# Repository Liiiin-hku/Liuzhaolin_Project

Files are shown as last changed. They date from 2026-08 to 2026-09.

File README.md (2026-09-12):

English · [中文](README_ZH.md)

# Compact Vision-Based Tactile Sensor for Robotic End Effectors

**Mechanical Design · Prototyping · Hardware Integration**<br>
**LIU Zhaolin | MSc Mechanical Engineering, The University of Hong Kong**

An engineering project bringing together compact sensor packaging, optical hardware, silicone fabrication and robotic mounting interfaces. Building on **9DTact**, I developed camera and enclosure adaptations, integrated illumination and internal routing, fabricated and assembled **two tactile sensor prototypes**, and built a test platform mechanically coupled to a **Robotiq FT300** six-axis force/torque sensor.

This portfolio follows the work from **CAD and component integration to physical prototypes and tactile contact demonstrations**, with engineering drawings, manufacturing records, software and experimental materials available to explore.

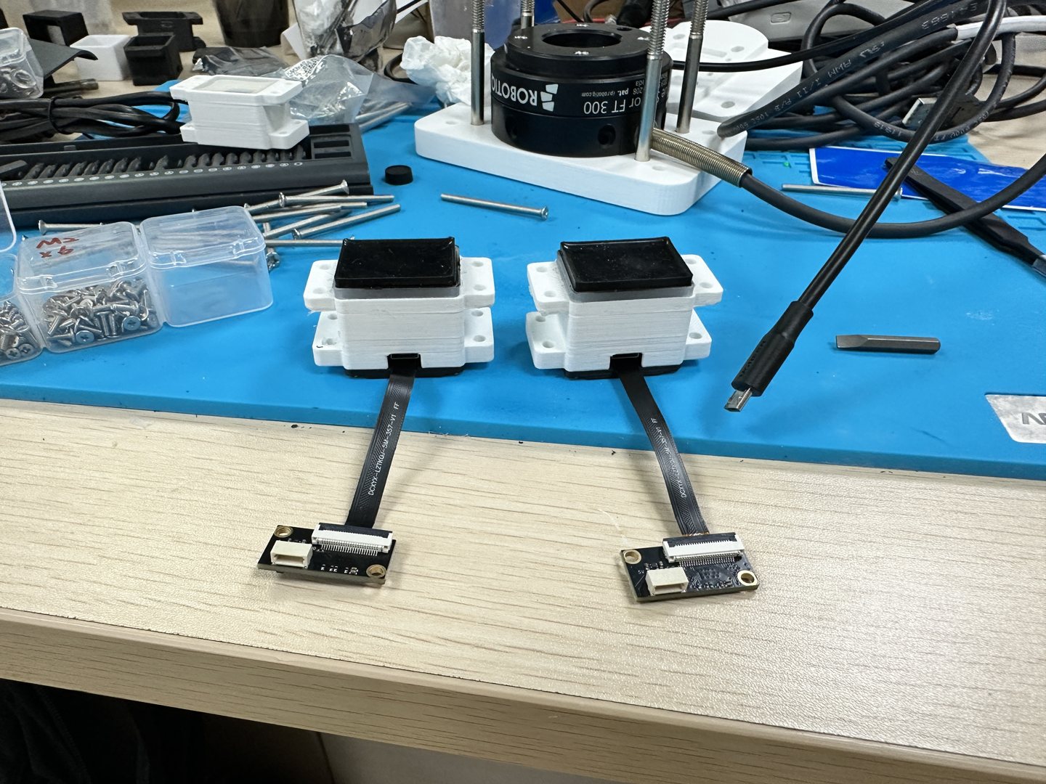
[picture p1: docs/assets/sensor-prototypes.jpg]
Two assembled tactile sensor prototypes with flexible camera cables and external decoder boards


*Two assembled prototypes showing the printed housings, tactile interfaces, flexible camera connections and external decoder boards.*

## Explore the project

| Start here | What you can review |
|---|---|
| [Mechanical design and hardware](03_Hardware/README.md) | Sensor parts, robotic mounting concepts, FT300 adapters, PCB integration and BOMs |
| [Prototype and contact demonstrations](05_Demos/README.md) | Short video extracts, original recordings and viewing instructions |
| [Engineering contributions](docs/PROJECT_OVERVIEW.md) | Responsibilities, design methods and supporting source files |
| [Software and system integration](02_Software/SOFTWARE_INDEX.md) | Camera calibration tools, reconstruction, FT300 workflows and ROS documentation |

**Quick hardware tour:** [22-second prototype video](05_Demos/Previews/hardware-preview.mp4) · [FT300 test platform](docs/assets/ft300-platform.jpg) · [Manufacturing photo collection](03_Hardware/08_Renders_and_Photos/PHOTO_CATALOG.md)

## My engineering contributions

| Workstream | Design and implementation |
|---|---|
| **Mechanical packaging** | Adapted the sensor housing, locating features, camera retention and optical-window support around an OV5640 imaging module and external decoder board. |
| **Optical and electrical integration** | Coordinated the lens, eight-LED illumination board and tactile window; arranged the flexible cable outlet and clearances around fasteners and the mechanical load path. |
| **Fabrication and assembly** | Prepared printed components and silicone moulds; carried out sealing, mixing, vacuum degassing, layered casting, curing, demoulding and prototype assembly. |
| **Image calibration and tactile experiments** | Implemented an interactive 7 × 9 calibration-point selection tool, worked on image rectification, and carried out spherical-indenter and contact-shape reconstruction experiments. |
| **Test fixtures and robotic interfaces** | Developed mounting adapters for the FT300-coupled platform and a two-finger gripper mounting concept, supported by CAD, STL files and assembly renderings. |
| **Software and ROS integration** | Organised sensor configurations and tools for FT300 acquisition, coordinate transforms, data checks, training/inference workflows and ROS Noetic operation. |

## Sensor architecture and compact packaging

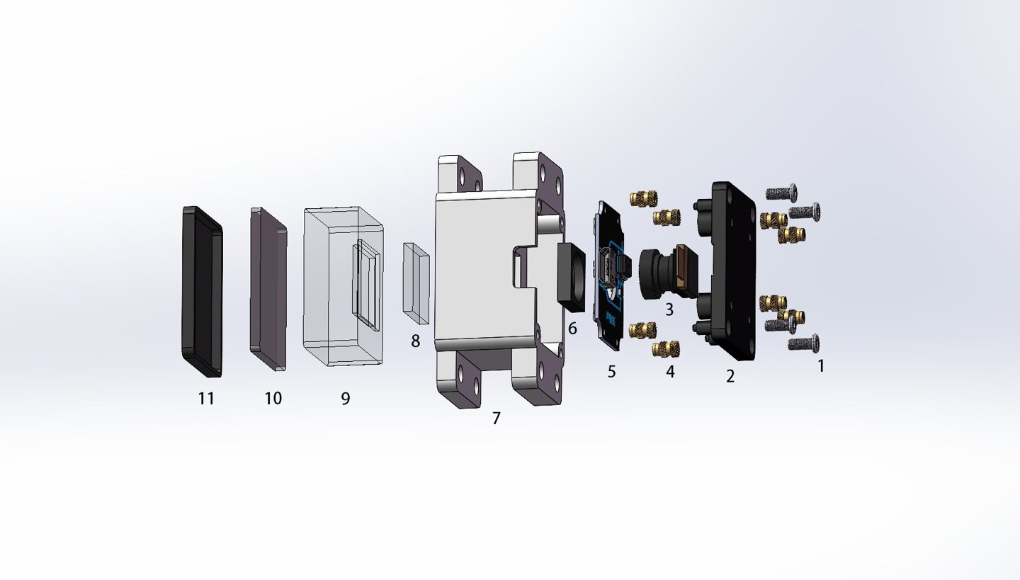
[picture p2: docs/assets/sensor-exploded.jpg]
Exploded view of the sensor housing, camera, illumination board, optical window and layered silicone interface


The mechanical design brings the camera, illumination, optical window and compliant tactile interface into a compact sensor head. Locating and retention features coordinate the optical stack, while an external decoder board connects through a flexible cable. Cable routing, assembly access and the mounting interface are considered alongside the sensor's optical requirements.

[Sensor CAD parts](03_Hardware/01_CAD_Source/SolidWorks_Parts/Optimized_Sensor/) · [STL models](03_Hardware/03_Print_Files_STL/README.md) · [Assembly and manufacturing records](03_Hardware/09_Manufacturing_Notes/ASSEMBLY_AND_MANUFACTURING_NOTES.md)

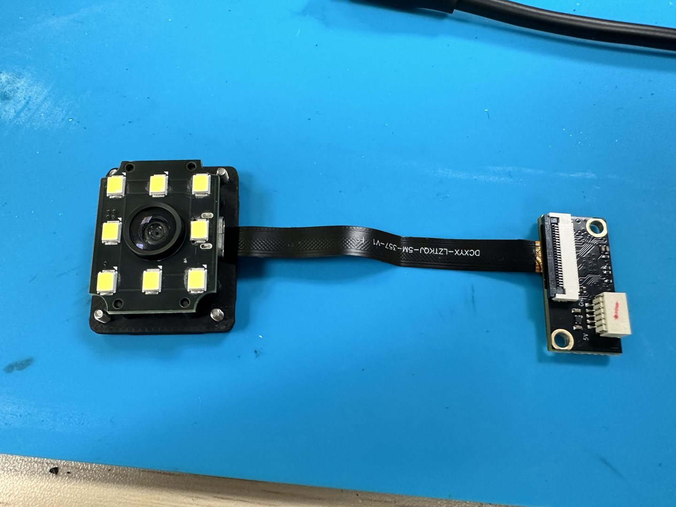
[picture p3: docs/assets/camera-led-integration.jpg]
Camera and eight-LED board integrated with the flexible cable and decoder


*Camera, illumination and cable integration. The LED PCB is reused from the upstream design; my work focuses on its mechanical placement, optical alignment and integration into the adapted sensor.*

## Silicone fabrication and prototype assembly

The tactile interface uses a layered silicone construction: a transparent **G50 support layer**, a translucent **G5 deformation layer** and a black **G25 contact layer**. The fabrication workflow covers mould preparation, seam sealing, mixing and vacuum degassing, successive casting and curing, followed by demoulding and final assembly.

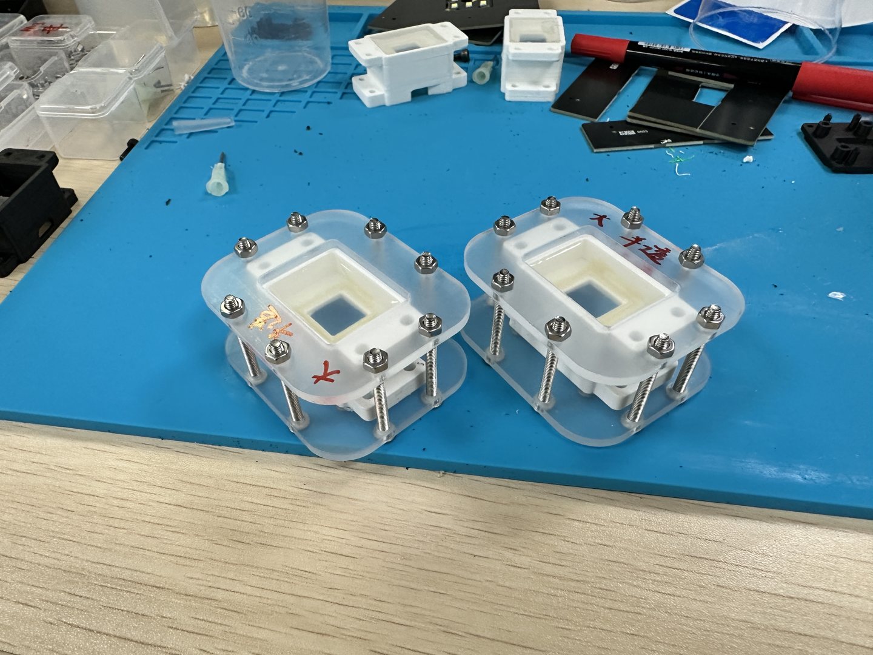
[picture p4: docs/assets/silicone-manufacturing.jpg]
Moulds and components used in the layered silicone fabrication process


The engineering archive includes **12 native SolidWorks part files, one LED-board assembly, nine STL files and three mould DXF files**, alongside component photographs, manufacturing records and bills of materials.

[Fabrication photographs](03_Hardware/09_Manufacturing_Notes/Process_Photos/) · [Mould drawings](03_Hardware/04_Engineering_Drawings/Acrylic_Mold/) · [BOM navigation](03_Hardware/BOM_INDEX.md)

## FT300 test platform and end-effector mounting

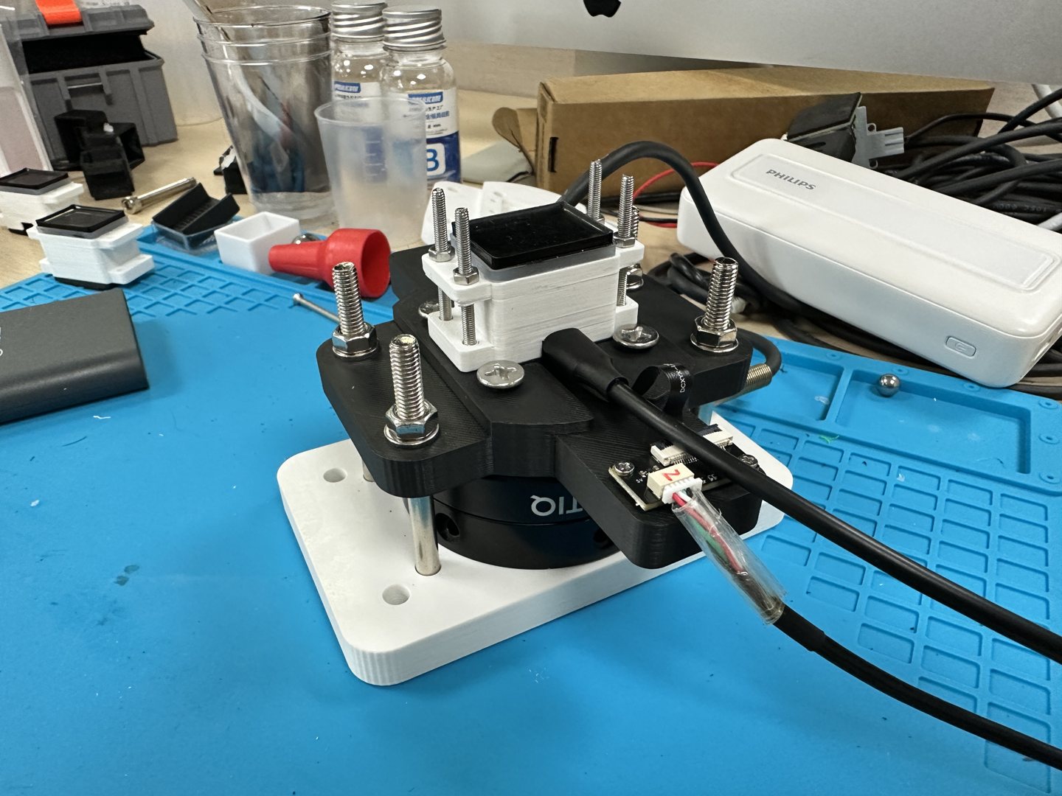
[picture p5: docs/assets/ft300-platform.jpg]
Custom tactile sensor mounted on a Robotiq FT300 mechanical test platform


The test fixture mechanically couples the tactile sensor to a **Robotiq FT300** reference force/torque sensor. Dedicated adapter parts provide a mounting interface and load-transfer path for contact experiments. The repository includes the physical setup, connection CAD and supporting acquisition workflows.

[FT300 adapter parts](03_Hardware/01_CAD_Source/SolidWorks_Parts/Test_Connections/) · [FT300 software setup](02_Software/Final_Repository_Snapshot/docs/06_FT300_SETUP.md)

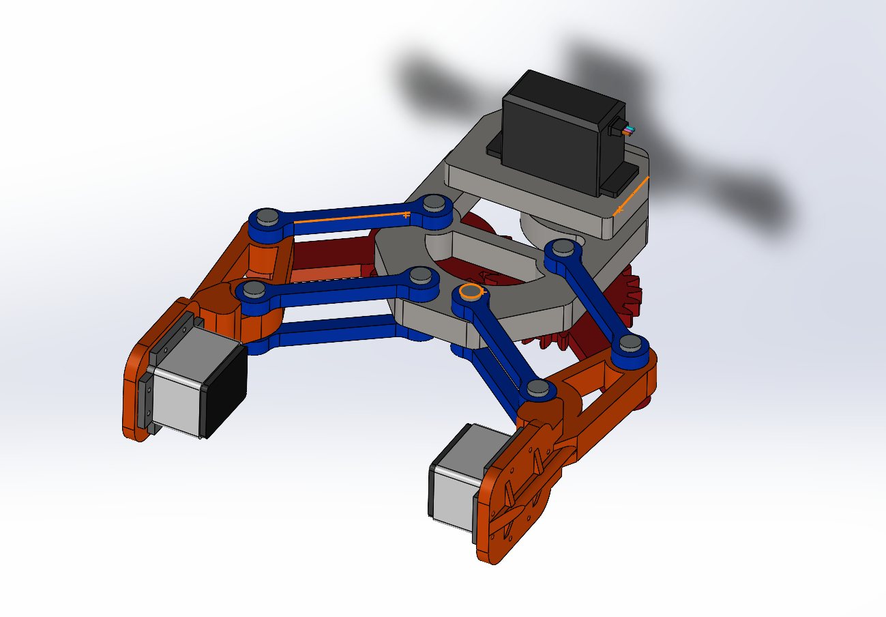
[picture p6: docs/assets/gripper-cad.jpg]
CAD rendering of a two-finger gripper concept with tactile sensor mounting interfaces


*Two-finger gripper mounting concept: left/right parts and sensor placement developed at the CAD stage.*

[Gripper CAD](03_Hardware/01_CAD_Source/SolidWorks_Parts/Gripper/) · [Gripper STL files](03_Hardware/03_Print_Files_STL/Existing_Source/Gripper/)

## Experiments and demonstrations

The project records show the assembled sensor, its connection to the computing environment, and tactile contact with an accompanying shape-reconstruction display. Calibration materials include point-selection images, spherical-indenter experiments and a reconstructed contact-shape example.

| Recording | View |
|---|---|
| Prototype appearance, illumination and connections | [22-second extract](05_Demos/Previews/hardware-preview.mp4) |
| Pressing interaction and shape response | [28-second extract](05_Demos/Previews/shape-preview.mp4) |
| Six-axis vector interface demonstration | [28-second extract](05_Demos/Previews/vector-preview.mp4) |

Open a video file and select **View raw** or **Download raw file** to watch. The [demo guide](05_Demos/README.md) provides original recordings, timestamps and interpretation. [Technical validation notes](docs/VALIDATION_STATUS.md) document experiment conditions and software checks.

## Engineering archive

| Area | Contents |
|---|---|
| [Academic work](01_Academic/ACADEMIC_INDEX.md) | Dissertation, presentation, project reports and reference index |
| [Software](02_Software/SOFTWARE_INDEX.md) | Frozen source snapshot, installation and operating guides |
| [Hardware](03_Hardware/README.md) | CAD, STL, DXF, PCB, BOM, photographs and manufacturing records |
| [Calibration and experiment materials](04_Data_and_Models/DATA_MODEL_INDEX.md) | Calibration files, process images and contact-shape results |
| [Demonstrations](05_Demos/README.md) | Video covers, short extracts and original recordings |

The documented software environment is **Ubuntu 20.04 / Python 3.8 / ROS Noetic**. Start with the [installation and workflow guide](02_Software/SOFTWARE_INDEX.md).

## Project background and attribution

This portfolio presents the engineering work associated with my master's dissertation, *Development of a Compact Vision-Based Tactile Sensor for Robotic End Effectors*.

The project builds on the [9DTact sensing methods and open-source design](https://github.com/linchangyi1/9DTact). Upstream algorithms, reference hardware and licences are retained with their attribution; project-specific adaptations and integration tools are documented in the source snapshot. The software reference commit is `98ebb7da0010df27ef634f9868e557d77fa73ec5`.

[Project timeline](PROGRESS_TIMELINE.md) · [Version provenance](VERSION_FREEZE.md) · [Rights and attribution](docs/RIGHTS_AND_ATTRIBUTION.md) · [File manifest](SUBMISSION_MANIFEST.csv)

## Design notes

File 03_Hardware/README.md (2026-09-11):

# 结构设计、样机与硬件资料

[返回首页](../README.md) · [个人贡献证据](../docs/PROJECT_OVERVIEW.md)

这里展示从结构适配到实物制造的工程材料。原始 CAD、装配体、PCB、BOM 和制造照片保持原路径；展示图片是压缩副本。

传感器结构爆炸图

## 先看结构和实物

| 主题 | 工程入口 | 可直接浏览的证据 |
|---|---|---|
| 外壳、基座、窗口和隔离环 | [Optimized_Sensor](01_CAD_Source/SolidWorks_Parts/Optimized_Sensor/) | [双传感器成品](08_Renders_and_Photos/Completed_Hardware/completed_dual_custom_sensors.jpg) |
| FT300 与传感器连接基座 | [Test_Connections](01_CAD_Source/SolidWorks_Parts/Test_Connections/) | [FT300 耦合平台](08_Renders_and_Photos/Test_Setups/sensor_ft300_calibration_fixture.jpg) |
| 双指夹爪安装方案 | [左右夹爪 CAD](01_CAD_Source/SolidWorks_Parts/Gripper/) | [装配渲染](08_Renders_and_Photos/Assembly_and_Design/custom_gripper_assembly_render.png) |
| 3D 打印交付 | [9 个 STL 与映射](03_Print_Files_STL/README.md) | [打印件照片](09_Manufacturing_Notes/Process_Photos/printed_mold_and_housing_parts.jpg) |
| 分层浇注模具 | [3 个亚克力 DXF](04_Engineering_Drawings/Acrylic_Mold/) | [模具及硅胶制造记录](09_Manufacturing_Notes/ASSEMBLY_AND_MANUFACTURING_NOTES.md) |

原生 SolidWorks 为 **12 个零件和 1 个 LED 板装配体**，不等同于完整的自定义传感器或夹爪装配工程。STL 为 9 个，其中 7 个为转换交付、2 个为既有夹爪 STL。本次未执行 SolidWorks 打开、重建、单位或装配引用检查；没有重命名或移动 CAD。

## PCB、照明和 BOM

- [PCB 工程、Gerber、贴片坐标与电子照片](07_PCB_and_Electronics/ELECTRONICS_INDEX.md)
- [主 BOM 与电子 BOM](BOM_INDEX.md)：主表 38 行材料/采购条目；电子表 4 行器件类型；贴片表 11 个位置。
- [电子实物：相机、LED 板、排线与解码板](07_PCB_and_Electronics/Photos/sensor_electronics_components.jpg)

主 BOM 用于器件和制造资料定位，采购单价与汇总并不代表单个样机的物料成本。保留的 PCB 工程、Gerber ZIP、电子 BOM 与贴片表与上游快照相同；个人工作按照明安装和硬件集成说明。[文件来源核对](../docs/HARDWARE_PROVENANCE.csv)

## 制造与装配

从 [制造记录](09_Manufacturing_Notes/ASSEMBLY_AND_MANUFACTURING_NOTES.md) 查看模具封边、混合脱泡、分层浇注、固化脱模和装配过程。完整 [图片目录](08_Renders_and_Photos/PHOTO_CATALOG.md) 与 [来源映射](08_Renders_and_Photos/PHOTO_SOURCE_MAPPING.csv) 保留原图线索。

仍缺与最终 CAD/BOM 逐项对应并经复核的装配步骤、完整端到端接线图及统一供电范围说明。实际制造前需要核实尺寸、孔隙配合、极性与电源条件；这些限制详见 [验证状态](../docs/VALIDATION_STATUS.md)。

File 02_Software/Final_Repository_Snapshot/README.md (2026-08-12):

# 9DTact + FT300 Custom Tactile Sensor Project

[Chinese README](README_CN.md) | [Version and validation status](VERSION_INFO.md)

This repository is the graduation-project delivery for two custom optical tactile
sensors derived from the 9DTact workflow. It brings together camera calibration,
3D surface reconstruction, synchronized FT300 data acquisition, dataset preparation,
six-axis force-model training, standalone tactile inference, and ROS 1 integration.

The repository is organized for a beginner to complete one sensor at a time. Sensor 1
and Sensor 2 keep separate calibration, dataset, configuration, and model paths. The
active sensor is selected explicitly before calibration, acquisition, reconstruction,
training, or inference.

> **Validation boundary:** repository structure and static checks can be verified on
> Windows. Camera mapping, depth response, FT300 acquisition, ROS nodes, trained-model
> accuracy, and combined hardware behavior still require Ubuntu 20.04 tests with the
> physical devices. No Windows result is presented as a hardware pass.

## Project scope

| Stage | Included implementation | Current evidence |
|---|---|---|
| Sensor selection | Isolated Sensor 1 and Sensor 2 templates and activation tool | Static file/configuration checks |
| Camera calibration | Automatic calibration plus a reviewed 7 x 9 manual-point workflow | Active arrays exist for both sensors; Sensor 2 has manual-point provenance |
| Depth-to-shape conversion | Active hybrid official depth LUT experiment | File integrity verified; physical accuracy remains unverified |
| Shape reconstruction | Standalone OpenCV/Open3D workflow and ROS wrapper | Requires Ubuntu camera test |
| FT300 acquisition | Synchronized tactile image and `WrenchStamped` label collection | Requires an external FT300 ROS driver and hardware test |
| Dataset processing | Integrity checks, normalization, and two object-disjoint split modes | Offline tools included |
| Force training | ResNet18 smoke-test path and DenseNet169 full-training path | Training code included; datasets and trained weights are excluded |
| Force inference | Standalone and ROS six-axis inference | Requires a sensor-specific checkpoint and Ubuntu test |
| ROS integration | Catkin package and six launch workflows | Static XML/Python checks only |

## Important calibration facts

- Each sensor resolves `row_index.npy`, `col_index.npy`, and `position_scale.npy`
  through a sensor-specific active path. The current three core arrays are
  byte-identical between those paths; they are not evidence of independently derived
  camera mappings.
- Both active sensors currently use the same official upstream depth lookup table:
  `Original/shape_reconstruction/calibration/sensor_1/depth_calibration/Pixel_to_Depth.npy`.
- The shared LUT SHA-256 is
  `19C9F3514DCE402D8E710079757394B5445B74E7AFBDD2459DE43798676CB4FF`.
- This is an **experimental hybrid calibration**, not an independently measured,
  precise depth calibration of either custom sensor.
- Running `shape_reconstruction/_2_Sensor_Calibration.py` trains and replaces the
  active sensor's LUT. Doing so intentionally leaves the hybrid-LUT state. Back up
  the current LUT first; if the hybrid state is restored, rerun
  `python tools/verify_hybrid_calibration.py`.
- The latest Ubuntu archive records `camera_channel: 2` and a reconstruction crop of
  `[280, 380]` for both sensors. `/dev/videoX` numbering is host-dependent and must be
  checked on every Ubuntu computer. Force-model `img_size` is aligned to `[280, 380]`.

## Supported baseline

- Ubuntu 20.04 LTS
- Python 3.8
- ROS Noetic (ROS 1)
- OpenCV, NumPy, SciPy, Open3D, and PyYAML from the pinned core requirements
- PyTorch 2.0.1 and torchvision 0.15.2 for training and inference
- An external FT300 ROS driver that publishes `geometry_msgs/WrenchStamped`

The repository does not bundle an FT300 hardware driver and does not claim that a
particular vendor driver officially supports ROS Noetic. Confirm the driver and robot
controller combination in the target laboratory. The raw wrench topic is configurable;
the example default is `/robotiq_ft_wrench`.

## Beginner quick start

### 1. Install the core Ubuntu environment

```bash
cd <LOCAL_PROJECT_ROOT>
bash scripts/install_core_ubuntu20.sh
source custom_9dtact/.venv/bin/activate
python scripts/verify_installation.py --profile core
```

For ROS or training dependencies, continue with
[Ubuntu 20.04 installation](docs/01_INSTALLATION_UBUNTU20.md). Do not copy a virtual
environment from another computer.

### 2. Select and check one sensor

```bash
cd <LOCAL_PROJECT_ROOT>/custom_9dtact
python tools/activate_sensor.py --sensor-id 1
python tools/check_sensor_setup.py --sensor-id 1
```

Use `--sensor-id 2` for Sensor 2. Activation copies the selected templates into the
active `shape_config.yaml` and `force_config.yaml` files and stores local runtime state
under `.runtime/`.

### 3. Confirm the camera device on Ubuntu

```bash
v4l2-ctl --list-devices
ls -l /dev/video*
```

If the correct device is not channel 2 on that host, edit the selected persistent
template in `custom_9dtact/configs/`, then activate the sensor again. Do not edit only
the generated active configuration.

### 4. Validate or rebuild camera calibration

Automatic workflow:

```bash
cd <LOCAL_PROJECT_ROOT>/custom_9dtact/shape_reconstruction
python _1_Camera_Calibration.py
```

Manual 7 x 9 workflow, with new reference/sample capture:

```bash
python manual_camera_calibration_v2.py --capture
```

Click 63 grid points in row-major order. Press `A` to toggle snapping, use right-click
or `U` to undo, press Enter to preview, and press lowercase `s` to save. The tool makes
a timestamped internal backup before replacing active camera arrays. See
[Camera calibration](docs/03_CAMERA_CALIBRATION.md) before applying new outputs.

### 5. Check the active hybrid depth LUT

```bash
cd <LOCAL_PROJECT_ROOT>/custom_9dtact
python tools/verify_hybrid_calibration.py
```

The check proves file identity and array validity only. It does not prove the physical
depth response of either custom sensor.

### 6. Run standalone 3D shape reconstruction

```bash
cd <LOCAL_PROJECT_ROOT>/custom_9dtact
python tools/activate_sensor.py --sensor-id 1
python tools/check_sensor_setup.py --sensor-id 1
cd shape_reconstruction
python _3_Shape_Reconstruction.py
```

Repeat in a fresh terminal with Sensor 2 selected. Record the no-contact surface,
light press, medium press, release recovery, and contact-location response separately.

### 7. Acquire FT300-labelled data

FT300 measurements are ground-truth labels for data collection, training, and
validation. Start the ROS master, camera/image publisher, and external FT300 driver
before starting the collector. Validate the wrench topic first:

```bash
cd <LOCAL_PROJECT_ROOT>/custom_9dtact
python tools/check_ft300_topic.py --topic /robotiq_ft_wrench
```

Then follow [FT300 setup](docs/06_FT300_SETUP.md) and
[data collection](docs/07_DATA_COLLECTION.md). Stop recording before stopping the
collector, then stop the camera and FT300 driver, and stop `roscore` last.

### 8. Prepare, train, and evaluate

Keep the two sensor datasets separate. Validate a dataset before training:

```bash
cd <LOCAL_PROJECT_ROOT>/custom_9dtact
python tools/check_dataset_integrity.py \
  --dataset-root Dataset_sensor_1 \
  --require-normalized \
  --check-splits
```

Run a short ResNet18 pipeline test before a long DenseNet169 run. Trained tactile
inference uses camera images and the selected neural-network checkpoint; FT300 is not
required during normal inference. FT300 remains necessary when collecting new labels
or comparing predictions against physical ground truth.

### 9. Run in ROS

The catkin package is located at
`custom_9dtact/ros_ws/src/9dtact_ft300_ros`. Its six launch entry points are:

- `sensor1_shape.launch`
- `sensor2_shape.launch`
- `ft300_collection.launch`
- `force_estimation.launch`
- `shape_force_demo.launch`
- `compare_prediction_with_ft300.launch`

Build, source, and use the launch file that matches the intended stage. Review the
actual launch-file arguments before starting hardware. See
[ROS workflow](docs/11_ROS_WORKFLOW.md).

## Documentation map

1. [Project overview](docs/00_PROJECT_OVERVIEW.md)
2. [Ubuntu 20.04 installation](docs/01_INSTALLATION_UBUNTU20.md)
3. [Sensor configuration](docs/02_SENSOR_CONFIGURATION.md)
4. [Camera calibration](docs/03_CAMERA_CALIBRATION.md)
5. [Sensor/depth calibration](docs/04_SENSOR_CALIBRATION.md)
6. [Shape reconstruction](docs/05_SHAPE_RECONSTRUCTION.md)
7. [FT300 setup](docs/06_FT300_SETUP.md)
8. [Data collection](docs/07_DATA_COLLECTION.md)
9. [Data processing](docs/08_DATA_PROCESSING.md)
10. [Model training](docs/09_MODEL_TRAINING.md)
11. [Force estimation](docs/10_FORCE_ESTIMATION.md)
12. [ROS workflow](docs/11_ROS_WORKFLOW.md)
13. [Troubleshooting](docs/12_TROUBLESHOOTING.md)
14. [Project tree](docs/13_PROJECT_TREE.md)
15. [Hybrid depth-LUT experiment record](docs/ORIGINAL_DEPTH_LUT_EXPERIMENT_2026-07-25.md)

## Repository protection and excluded artifacts

- Treat `Original/` as a byte-preserved, read-only upstream snapshot.
- Work in `custom_9dtact/` and repository-level documentation only.
- Datasets, trained weights, local runtime state, caches, logs, temporary outputs,
  and generated training bundles are intentionally excluded from Git.
- Do not exchange calibration files, datasets, or model paths between Sensor 1 and
  Sensor 2.
- Back up active calibration and data before every hardware experiment.

## Citation and license

The custom work is distributed under the repository [LICENSE](LICENSE). Upstream
attribution and third-party notices are recorded in [NOTICE.md](NOTICE.md). When this
project is used in academic work, cite the upstream 9DTact project and the relevant
hardware/software sources described there.

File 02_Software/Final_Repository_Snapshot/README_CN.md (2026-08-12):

# 9DTact + FT300 自制触觉传感器项目

[English README](README.md) | [版本与验证状态](VERSION_INFO.md)

本仓库是面向毕业设计交付的双自制光学触觉传感器代码工程，基于 9DTact 工作流，覆盖摄像头标定、
三维形状重建、FT300 同步数据采集、数据集处理、六维力模型训练、独立触觉推理和 ROS 1 集成。

Sensor 1 与 Sensor 2 的标定文件、配置、数据集和模型目录彼此隔离。标定、采集、重建、训练或推理前，
一次只激活一个传感器。

> **验证边界：** Windows 已完成的内容属于仓库结构和静态检查，不代表相机、深度响应、FT300、ROS、
> 模型精度或组合硬件测试通过。相关结论仍需在 Ubuntu 20.04 连接真实硬件后逐项验证。

## 当前项目状态

| 环节 | 仓库内容 | 当前证据 |
|---|---|---|
| 传感器切换 | Sensor 1/2 独立模板与激活工具 | 已完成静态配置检查 |
| 摄像头标定 | 自动流程和 7 x 9 手动点选流程 | 两个传感器活动数组存在；Sensor 2 有手动点来源记录 |
| 深度到形状转换 | 官方深度 LUT 混合实验 | 文件一致性通过；物理准确性待实测 |
| 三维形状重建 | 独立程序与 ROS 封装 | 待 Ubuntu 相机实测 |
| FT300 采集 | 图像与 `WrenchStamped` 六维力同步采集 | 需要外部 FT300 驱动和硬件实测 |
| 数据处理 | 完整性检查、归一化以及两种按物体隔离的划分方式 | 离线工具已提供 |
| 力模型训练 | ResNet18 短训练和 DenseNet169 正式训练流程 | 代码已提供；数据集和权重未包含在仓库中 |
| 力推理 | 独立与 ROS 六维力推理 | 需要传感器对应权重并在 Ubuntu 验证 |

## 标定状态必须如实理解

- Sensor 1 和 Sensor 2 分别通过各自的活动路径使用 `row_index.npy`、`col_index.npy` 和
  `position_scale.npy`。当前两个路径中的三份核心数组内容逐字节相同，因此不能据此描述为两个独立生成的
  摄像头映射。
- 两个传感器当前活动的 `Pixel_to_Depth.npy` 都来自上游只读快照中的
  `Original/shape_reconstruction/calibration/sensor_1/depth_calibration/Pixel_to_Depth.npy`。
- 共享 LUT 的 SHA-256 为
  `19C9F3514DCE402D8E710079757394B5445B74E7AFBDD2459DE43798676CB4FF`。
- 当前方案属于实验性混合标定，不等同于分别对两个自制传感器完成了精确深度标定。
- 执行 `shape_reconstruction/_2_Sensor_Calibration.py` 会训练并替换当前活动传感器的 LUT，
  因此会主动退出混合官方 LUT 状态。执行前应备份；如需恢复混合方案，恢复后再次运行
  `python tools/verify_hybrid_calibration.py`。
- 最新 Ubuntu 压缩包中两个传感器均记录 `camera_channel: 2`，形状裁剪尺寸均为 `[280, 380]`，
  力模型 `img_size` 已与其对齐。`/dev/videoX` 编号取决于具体电脑，必须在目标 Ubuntu 主机重新确认。

## 环境基线

- Ubuntu 20.04 LTS
- Python 3.8
- ROS Noetic
- 核心依赖：OpenCV、NumPy、SciPy、Open3D、PyYAML
- 训练依赖：PyTorch 2.0.1、torchvision 0.15.2、TensorBoard
- 外部 FT300 ROS 驱动：必须发布可配置话题类型 `geometry_msgs/WrenchStamped`

仓库不包含 FT300 硬件驱动，也不声称某个厂商驱动获得 ROS Noetic 官方支持。默认示例原始力话题为
`/robotiq_ft_wrench`，实际话题可以配置。

## 新手快速流程

### 1. 安装核心环境

```bash
cd <LOCAL_PROJECT_ROOT>
bash scripts/install_core_ubuntu20.sh
source custom_9dtact/.venv/bin/activate
python scripts/verify_installation.py --profile core
```

ROS 与训练依赖见 [Ubuntu 20.04 安装说明](docs/01_INSTALLATION_UBUNTU20.md)。不要从另一台电脑复制虚拟环境。

### 2. 激活并检查一个传感器

```bash
cd <LOCAL_PROJECT_ROOT>/custom_9dtact
python tools/activate_sensor.py --sensor-id 1
python tools/check_sensor_setup.py --sensor-id 1
```

Sensor 2 将参数改为 `--sensor-id 2`。如目标电脑中的相机不是通道 2，应先修改
`custom_9dtact/configs/` 中对应模板，再重新激活。

### 3. 校验或重新生成摄像头标定

自动标定：

```bash
cd <LOCAL_PROJECT_ROOT>/custom_9dtact/shape_reconstruction
python _1_Camera_Calibration.py
```

手动 7 x 9 点选并重新拍摄参考图与样本图：

```bash
python manual_camera_calibration_v2.py --capture
```

按行优先顺序点击 63 个点；`A` 切换吸附；鼠标右键或 `U` 撤销；Enter 预览；小写 `s` 保存。
工具会在覆盖活动数组前创建带时间戳的内部备份。完整步骤见
[摄像头标定](docs/03_CAMERA_CALIBRATION.md)。Sensor 2 当前有手动点来源记录；Sensor 1 的活动数组没有独立的
手动点源文件，因此不要把其来源描述为可独立重现的手动点选结果。

### 4. 校验混合深度 LUT

```bash
cd <LOCAL_PROJECT_ROOT>/custom_9dtact
python tools/verify_hybrid_calibration.py
```

该命令只证明文件哈希、数组形状和有限性满足检查条件，不证明真实物理深度响应准确。

### 5. 运行三维形状重建

```bash
cd <LOCAL_PROJECT_ROOT>/custom_9dtact
python tools/activate_sensor.py --sensor-id 1
python tools/check_sensor_setup.py --sensor-id 1
cd shape_reconstruction
python _3_Shape_Reconstruction.py
```

Sensor 2 必须在新的终端会话中独立激活和测试。分别记录无接触平整度、轻压显示、中压连续性、松开恢复和
接触位置是否正确。

### 6. 采集 FT300 标签数据

FT300 在本项目中用于训练和验证的真实六维力标签。应依次启动 ROS master、触觉图像发布节点、外部 FT300
驱动，再启动采集程序。采集前先检查话题：

```bash
cd <LOCAL_PROJECT_ROOT>/custom_9dtact
python tools/check_ft300_topic.py --topic /robotiq_ft_wrench
```

完整步骤见 [FT300 设置](docs/06_FT300_SETUP.md) 和
[数据采集](docs/07_DATA_COLLECTION.md)。结束时先停止记录，再停止采集器，然后停止相机和 FT300 驱动，
最后停止 `roscore`。

### 7. 数据处理、训练与推理

两个传感器的数据集和模型必须分开。训练前运行：

```bash
cd <LOCAL_PROJECT_ROOT>/custom_9dtact
python tools/check_dataset_integrity.py \
  --dataset-root Dataset_sensor_1 \
  --require-normalized \
  --check-splits
```

先用 ResNet18 做短训练检查，再进行 DenseNet169 正式训练。正常的神经网络触觉推理只依赖相机图像和对应
模型权重，不依赖 FT300；只有采集新标签或将预测与真实力比较时需要 FT300。

### 8. ROS 工作流

Catkin 包位于 `custom_9dtact/ros_ws/src/9dtact_ft300_ros`，包含以下六个入口：

- `sensor1_shape.launch`
- `sensor2_shape.launch`
- `ft300_collection.launch`
- `force_estimation.launch`
- `shape_force_demo.launch`
- `compare_prediction_with_ft300.launch`

使用前阅读实际 launch 文件参数，完整顺序见 [ROS 工作流](docs/11_ROS_WORKFLOW.md)。

## 完整文档

- [项目概览](docs/00_PROJECT_OVERVIEW.md)
- [Ubuntu 20.04 安装](docs/01_INSTALLATION_UBUNTU20.md)
- [传感器配置](docs/02_SENSOR_CONFIGURATION.md)
- [摄像头标定](docs/03_CAMERA_CALIBRATION.md)
- [传感器/深度标定](docs/04_SENSOR_CALIBRATION.md)
- [形状重建](docs/05_SHAPE_RECONSTRUCTION.md)
- [FT300 设置](docs/06_FT300_SETUP.md)
- [数据采集](docs/07_DATA_COLLECTION.md)
- [数据处理](docs/08_DATA_PROCESSING.md)
- [模型训练](docs/09_MODEL_TRAINING.md)
- [力估计](docs/10_FORCE_ESTIMATION.md)
- [ROS 工作流](docs/11_ROS_WORKFLOW.md)
- [故障排查](docs/12_TROUBLESHOOTING.md)
- [项目目录](docs/13_PROJECT_TREE.md)
- [官方深度 LUT 混合实验记录](docs/ORIGINAL_DEPTH_LUT_EXPERIMENT_2026-07-25.md)

## 仓库保护规则

- `Original/` 是字节级保留的上游只读快照，不应修改、删除或重命名其中任何文件。
- 数据集、模型权重、`.runtime/`、缓存、日志、临时输出和训练包不进入 Git。
- 不得交换 Sensor 1 与 Sensor 2 的标定文件、数据集或模型路径。
- 每次真实硬件实验前备份活动标定与数据。

许可证见 [LICENSE](LICENSE)，上游与第三方说明见 [NOTICE.md](NOTICE.md)。

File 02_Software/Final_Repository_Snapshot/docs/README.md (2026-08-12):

# Documentation Index

This compatibility index replaces the earlier unnumbered workflow notes. Use the
numbered guides as the maintained documentation set:

1. [Project overview](00_PROJECT_OVERVIEW.md)
2. [Ubuntu 20.04 installation](01_INSTALLATION_UBUNTU20.md)
3. [Sensor configuration](02_SENSOR_CONFIGURATION.md)
4. [Camera calibration](03_CAMERA_CALIBRATION.md)
5. [Sensor and depth calibration](04_SENSOR_CALIBRATION.md)
6. [3D shape reconstruction](05_SHAPE_RECONSTRUCTION.md)
7. [FT300 setup](06_FT300_SETUP.md)
8. [Data collection](07_DATA_COLLECTION.md)
9. [Data processing](08_DATA_PROCESSING.md)
10. [Model training](09_MODEL_TRAINING.md)
11. [Force estimation](10_FORCE_ESTIMATION.md)
12. [ROS workflow](11_ROS_WORKFLOW.md)
13. [Troubleshooting](12_TROUBLESHOOTING.md)
14. [Project tree](13_PROJECT_TREE.md)

The [hybrid depth-LUT experiment record](ORIGINAL_DEPTH_LUT_EXPERIMENT_2026-07-25.md)
documents the active LUT source, limitation, validation, and rollback procedure.

Return to the [English repository README](../README.md) or
[Chinese repository README](../README_CN.md).

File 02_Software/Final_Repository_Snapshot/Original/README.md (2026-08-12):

# 9DTact
### Feel free to use this open-source project for commercial purposes!

# Table of contents
1. [Overview](#overview)
2. [Installation](#installation)
3. [3D Shape Reconstruction](#reconstruction)
   1. [Camera Calibration](#camera_calibration)
   2. [Sensor Calibration](#sensor_calibration)
   3. [Shape Reconstruction](#shape_reconstruction)
4. [6D Force Estimation](#estimation)
   1. [BOTA Driver](#bota)
   2. [Data Collection](#collection)
   3. [Data Processing](#processing)
   4. [Model Training](#training)
   5. [Force Estimation](#inference)
5. [Run in ROS](#ros)
   1. [Shape Reconstruction in ROS](#shape_ros)
   2. [Force Estimation in ROS](#force_ros)
   3. [Simultaneous Shape Reconstruction and Force Estimation (SSAF) in ROS](#shape_force)
6. [DTact Series Papers](#papers)

## Overview 
**This repository contains the code and the hardware source files for the paper:**

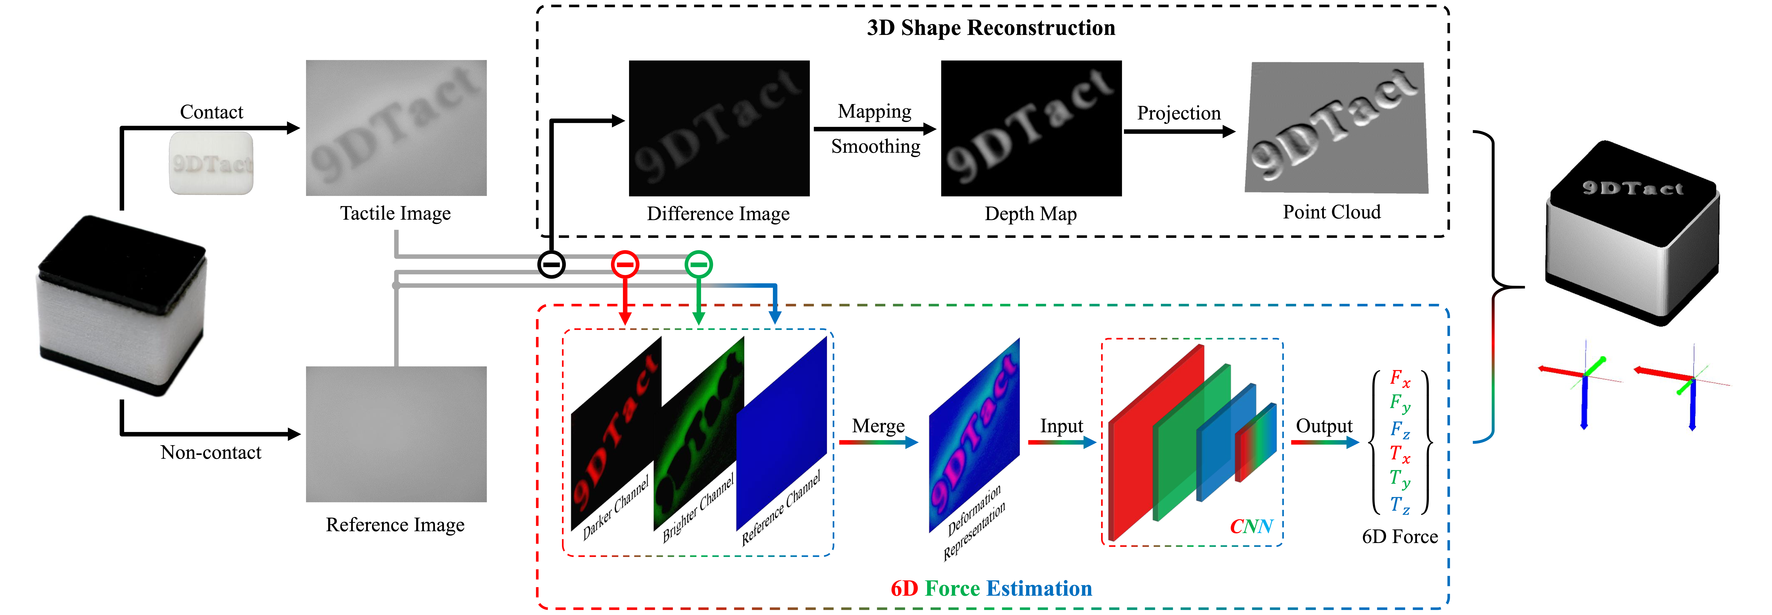
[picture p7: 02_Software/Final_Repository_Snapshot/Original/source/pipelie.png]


<b>9DTact: A Compact Vision-Based Tactile Sensor for Accurate 3D Shape Reconstruction and Generalizable 6D Force Estimation</b> <br>
[Changyi Lin](https://linchangyi1.github.io/),
[Han Zhang](https://doublehan07.github.io/),
Jikai Xu, Lei Wu, and
[Huazhe Xu](http://hxu.rocks/) <br>
RAL, 2023 <br>
[Website](https://linchangyi1.github.io/9DTact/) /
[Arxiv Paper](https://arxiv.org/abs/2308.14277) /
[Video Tutorial](https://www.youtube.com/watch?v=-oRtW398JDY) /
[Bom (CN)](https://docs.google.com/document/d/1d8c0Pbj_9otzWVxE94c6c-DW61ETBbJZIjVFKe4_OXI/edit?usp=sharing) /
[Production](https://e.tb.cn/h.hJlaI3aoyO30DGk?tk=K9Vm4iYdHwj)

## Installation 
#### Create a conda environment:
```bash
conda create -n 9dtact python=3.8
```
#### Install pytorch (choose the version that is compatible with your computer):
```bash
conda activate 9dtact
conda install pytorch torchvision torchaudio pytorch-cuda=11.8 -c pytorch -c nvidia
```
#### In this repository, install the other requirements:
```bash
pip install -e .
```

## 3D Shape Reconstruction 
For all the terminals used in this section, they are located in the **shape_reconstruction** directory and based on the **9dtact** conda environment:
```bash
cd shape_reconstruction
conda activate 9dtact
```

If you are using the **production** version of 9DTact, you do **not** need to calibrate the camera and sensor.
Please proceed directly to Step 3 (Shape Reconstruction).

### 1. Camera Calibration 
Before getting started, **adjust the camera focus** by rotating the lens until objects approximately 15 mm away appear clear.

Then, 3d print the [calibration board](9DTact_Design/fabrication/calibration_board.STL).<br>
Run:
```bash
python _1_Camera_Calibration.py
```
Just follow the printed instructions.

### 2. Sensor Calibration 
Firstly, prepare a ball with a radius of 4.0 mm.
(The radius of the ball depends on the thickness of the sensor surface.
4.0 mm is just a recommendation.)<br>
Then, run:
```bash
python _2_Sensor_Calibration.py
```
Just follow the printed instructions.

### 3. Shape Reconstruction 
```bash
python _3_Shape_Reconstruction.py
```
Press 'y' when the tactile image is stably captured, which will served as the reference image.

## 6D Force Estimation 
### 1. BOTA Driver 
**If you want to collect force data with a BOTA MiniONE Pro sensor, you need to:**<br>
Create a directory named 'bota_ws' as the ROS workspace, and install the [bota driver package](https://gitlab.com/botasys/bota_driver).

### 2. Data Collection 
#### At the first terminal, open the BOTA sensor:
```bash
cd ~/xxx/bota_ws # Modify 'xxx' to enter the workspace directory
source devel/setup.bash
roslaunch rokubimini_serial rokubimini_serial.launch
```
#### At the second terminal, run:
```bash
source ~/xxx/bota_ws/devel/setup.bash
cd data_collection
conda activate 9dtact
python collect_data.py
```
#### At the third terminal, open the 9DTact sensor:
```bash
cd shape-force-ros
conda activate 9dtact
python _1_Sensor_ros.py
```

### 3. Data Processing 
#### Open a terminal, normalize the wrench:
```bash
cd data_collection
conda activate 9dtact
python wrench_normalization.py  # remember to modify the object_num
```
#### At the same terminal, split the data by running:
```bash
python split_train_test.py
```
and also:
```bash
python split_train_test(objects).py
```

### 4. Model Training 
To train the model on the stadard training dataset, run:
```bash
cd force_estimation
python train.py --model_name="Densenet" --model_layer=169 --optimizer="ADAM" --lrs=False --image_type="RGB" --cuda_index=6 --resize_img=False --train_mode=True --test_object=False --mixed_image=True --pretrained=False --batch_size=64 --num_epoch=200 --learning_rate=5.0e-4 --weight_decay=0.0
```
You may also choose to use [Weights and Bias (wandb)](https://docs.wandb.ai/quickstart) by setting use_wandb as True,
which helps to track the training performance.

### 5. Force Estimation 
You need to specify a model saved in the 'saved_models' directory as an estimator,
by modifying the 'weights' parameters in the [force_config.yaml](force_estimation/force_config.yaml).<br>
After that, run:
```bash
cd force_estimation
python _1_Force_Estimation.py
```

## Run in ROS 
### 1. Shape Reconstruction in ROS 
#### At the first terminal, open the 9DTact sensor:
```bash
cd shape-force_ros
conda activate 9dtact
python _1_Sensor_ros.py
```
#### At the second terminal, run:
```bash
cd shape-force_ros
conda activate 9dtact
python _2_Shape_Reconstruction_ros.py
```

### 2. Force Estimation in ROS 
#### At the first terminal, open the 9DTact sensor:
```bash
cd shape-force_ros
conda activate 9dtact
python _1_Sensor_ros.py
```
#### At the second terminal, run:
```bash
cd shape-force_ros
conda activate 9dtact
python _3_Force_Estimation_ros.py
```
#### (Optional for visualization) At the third terminal, open the visualization window:
```bash
cd force_estimation
conda activate 9dtact
python force_visualizer.py
```
### 3. Simultaneous Shape Reconstruction and Force Estimation (SSAF) in ROS 
#### At the first terminal, open the force estimator:
```bash
cd shape-force_ros
conda activate 9dtact
python _3_Force_Estimation_ros.py
```
#### At the second terminal, run:
```bash
cd shape-force_ros
conda activate 9dtact
python _4_Shape_Force_ros.py
```
## DTact Series Papers 
- [DTact: A Vision-Based Tactile Sensor that Measures High-Resolution 3D Geometry Directly from Darkness](https://arxiv.org/abs/2209.13916), Lin et al., ICRA 2023
- [9DTact: A Compact Vision-Based Tactile Sensor for Accurate 3D Shape Reconstruction and Generalizable 6D Force Estimation](https://arxiv.org/abs/2308.14277), Lin et al., RAL 2023
- [Design and Evaluation of a Rapid Monolithic Manufacturing Technique for a Novel Vision-Based Tactile Sensor: C-Sight](https://www.mdpi.com/1424-8220/24/14/4603), Fan et al., MDPI Sensors 2024
- [DTactive: A Vision-Based Tactile Sensor with Active Surface](https://arxiv.org/abs/2410.08337), Xu et al., IROS 2025
- [VET: A Visual-Electronic Tactile System for Immersive Human-Machine Interaction](https://arxiv.org/pdf/2503.23440), Zhang et al., arxiv 2025
- [PP-Tac: Paper Picking Using Tactile Feedback in Dexterous Robotic Hands](https://arxiv.org/abs/2504.16649), Lin et al., RSS 2025
- [AllTact Fin Ray: A Compliant Robot Gripper with Omni-Directional Tactile Sensing](https://arxiv.org/pdf/2504.18064), Liang et al., arxiv 2025
- [SuperMag: Vision-based Tactile Data Guided High-resolution Tactile Shape Reconstruction for Magnetic Tactile Sensors](https://arxiv.org/pdf/2507.20002), Hou et al., IROS 2025
- [UTact: Underwater Vision-Based Tactile Sensor with Geometry Reconstruction and Contact Force Estimation](https://advanced.onlinelibrary.wiley.com/doi/pdfdirect/10.1002/adrr.202500091), Zhang et al., Advanced Robotics Research 2025
- [exUMI: Extensible Robot Teaching System with Action-aware Task-agnostic Tactile Representation](https://openreview.net/attachment?id=b86nyIOJWq&name=pdf), Xu et al., CoRL 2025
- [TacScope: A Miniaturized Vision-Based Tactile Sensor for Surgical Applications](https://advanced.onlinelibrary.wiley.com/doi/10.1002/adrr.202500117), Prince et al., Advanced Robotics Research 2025
- [Design and application of multimodal visual-tactile sensor for object information perception](https://www.sciencedirect.com/science/article/pii/S0924424726000804?via%3Dihub), Wang et al., Sensors and Actuators 2026
- [A Low-Cost Vision-Based Tactile Gripper with Pretraining Learning for Contact-Rich Manipulation](https://arxiv.org/pdf/2602.00514), Liu et al., arxiv 2026
- [SpikingTac: A Miniaturized Neuromorphic Visuotactile Sensor for High-Precision Dynamic Tactile Imprint Tracking](https://arxiv.org/pdf/2602.23654), Jiang et al., arxiv 2026

## Reference
```
@inproceedings{lin2023dtact,
  title={Dtact: A vision-based tactile sensor that measures high-resolution 3d geometry directly from darkness},
  author={Lin, Changyi and Lin, Ziqi and Wang, Shaoxiong and Xu, Huazhe},
  booktitle={2023 IEEE International Conference on Robotics and Automation (ICRA)},
  pages={10359--10366},
  year={2023},
  organization={IEEE}
}
```
```
@article{lin20239dtact,
  title={9dtact: A compact vision-based tactile sensor for accurate 3d shape reconstruction and generalizable 6d force estimation},
  author={Lin, Changyi and Zhang, Han and Xu, Jikai and Wu, Lei and Xu, Huazhe},
  journal={IEEE Robotics and Automation Letters},
  volume={9},
  number={2},
  pages={923--930},
  year={2023},
  publisher={IEEE}
}
```

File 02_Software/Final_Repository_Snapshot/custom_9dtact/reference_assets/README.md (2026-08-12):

# 作者参考标定说明

原作者的参考标定文件位于 `../Original/shape_reconstruction/calibration`。该路径以
`custom_9dtact` 项目根目录为起点，实际内容保存在 GitHub 仓库根目录的只读
`Original/` 快照中。

Sensor 1 和 Sensor 2 是两个自制传感器，必须分别完成 Camera Calibration 和
Sensor Calibration，不能直接使用原作者的标定结果，也不能互相复制标定结果。

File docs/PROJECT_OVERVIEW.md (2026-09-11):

# 项目概览与个人贡献证据

[返回首页](../README.md) · [硬件导航](../03_Hardware/README.md) · [验证状态](VALIDATION_STATUS.md)

项目面向机器人末端有限安装空间中的视触觉感知。机械工作围绕新相机的安装、镜头与照明对准、硅胶界面制造、排线保护和外部加载接口展开，形成两套样机及 FT300 机械耦合平台。

## 负责内容、方法与证据

| 负责内容 | 设计或实现方法 | 对应材料 | 已有验证及边界 |
|---|---|---|---|
| 传感器结构适配 | 调整外壳与基座，协调相机固定、窗口支撑、安装耳与排线间隙 | [Optimized_Sensor CAD](../03_Hardware/01_CAD_Source/SolidWorks_Parts/Optimized_Sensor/)；[爆炸图](assets/sensor-exploded.jpg)；论文第 4 章 | 成品照片和装配记录；本次未打开 SolidWorks 重建，完整定制装配体及 STEP 尚缺 |
| 相机重新选型和定位 | OV5640 相机头内置、解码板外置，通过柔性排线连接 | [电子实物](../03_Hardware/07_PCB_and_Electronics/Photos/sensor_electronics_components.jpg)；[主 BOM](../03_Hardware/05_BOM/Mechanical/Project_Master_BOM.xlsx)；答辩第 5 页 | 实物安装可见；未测光学一致性或批次重复性 |
| 照明与布线集成 | 将八 LED 板与镜头、窗口协调安装；排线避开紧固件与主要载荷路径 | [LED/相机特写](../03_Hardware/07_PCB_and_Electronics/Photos/led_pcb_and_camera.jpg)；[PCB 来源核对](HARDWARE_PROVENANCE.csv) | 安装照片支持集成工作；现存 PCB 源文件与上游相同，独立原创电路设计待补证据 |
| 模具、硅胶制备和样机装配 | 打印及亚克力模具，封边、混合、脱泡、逐层浇注、固化脱模 | [制造过程照片](../03_Hardware/09_Manufacturing_Notes/Process_Photos/)；[DXF](../03_Hardware/04_Engineering_Drawings/Acrylic_Mold/)；论文 4.5–4.8 | 两套成品及过程记录；缺分层厚度统计、气泡率、寿命或材料试验 |
| 手动相机图像校正 | 7 × 9 点有序选择，辅助放大、撤销、预览，再调用 RBF 映射 | [实际脚本](../02_Software/Final_Repository_Snapshot/custom_9dtact/shape_reconstruction/manual_camera_calibration_v2.py)；[标定过程图片](../04_Data_and_Models/02_Calibration_Data/Documentation_Images/Camera_Calibration/) | 63 点脚本和映射数组存在；两套核心数组相同，Sensor 1 独立点选来源不足 |
| 深度与形貌实验 | 球形压头、图像差分及像素到深度映射，观察螺纹接触形貌 | [压头与过程](../04_Data_and_Models/02_Calibration_Data/Documentation_Images/Depth_Calibration/)；[形貌结果](../04_Data_and_Models/03_Processed_Data/Shape_Reconstruction_Results/shape_reconstruction_result.png) | 有实验与定性结果；活动 LUT 复用上游，未提供独立深度误差指标 |
| FT300 机械耦合与加载平台 | 设计传感器和 FT300 连接基座，建立载荷传递路径 | [连接零件](../03_Hardware/01_CAD_Source/SolidWorks_Parts/Test_Connections/)；[平台实物](assets/ft300-platform.jpg)；论文 6.1 | 平台和独立读数的历史描述；缺冻结的置零、变换及完整采集会话日志 |
| 夹爪安装机构 | 保留左右夹爪零件及双传感器朝向抓取区域的装配方案 | [夹爪 CAD](../03_Hardware/01_CAD_Source/SolidWorks_Parts/Gripper/)；[夹爪 STL](../03_Hardware/03_Print_Files_STL/Existing_Source/Gripper/)；[渲染](assets/gripper-cad.jpg) | CAD 方案级；没有可核实的 R5 型号关联、实物抓取或触觉控制实验 |
| 数据与 ROS 集成 | 参数化 FT300 topic、置零/坐标变换、同步三元组、数据检查、训练/推理入口和六个 ROS launch | [数据采集代码](../02_Software/Final_Repository_Snapshot/custom_9dtact/data_collection/collect_data_ft300.py)；[ROS 工作流](../02_Software/Final_Repository_Snapshot/docs/11_ROS_WORKFLOW.md) | 代码实现与离线测试通过；未完成可复核的自制传感器六维力模型定量闭环 |

## 与上游的边界

`Original/` 保存 9DTact 原始代码、设计与许可。本项目沿用其感知原理、RBF 校正和形貌处理路线，新增或适配的脚本不意味着上游算法成为本项目原创。新增工具集中在 `custom_9dtact/`，详见 [冻结快照 Notice](../02_Software/Final_Repository_Snapshot/NOTICE.md)。

本次按 SHA-256 对比外层硬件与快照 `Original/`。13 个原生 SolidWorks 文件中，7 个与上游文件完全相同，包括 LED 板模型、标定板、亚克力窗口和隔离环；其余 6 个文件与该快照不相同。**字节不同只说明文件版本不同，本身不能证明原创设计。** [硬件来源清单](HARDWARE_PROVENANCE.csv) 记录所有外层工程文件的对应关系。

LED PCB 的 `.epro`、Gerber ZIP、电子 BOM、贴片坐标完全相同。部分展开 Gerber 文件有字节差异，尚未证明属于电路修改，不用它们支持独立 PCB 设计主张。

## 尺寸与夹爪型号

“体积缩减约 30%”尚未找到可重算的比较对。答辩 PDF 第 9 页写有约 42 × 38 × 34 mm，但没有明确是否包含安装耳、排线、外置解码板和加载夹具。本次 STL 包络检查仅辅助识别模型范围，STL 无单位，且单个外壳不代表整套系统体积。因此首页不使用缩减百分比。

可见夹爪资料被论文描述为自制双指夹爪装配；没有原厂型号、接口图或装配引用将其闭环到“方舟无限 R5”。保留这条待补证据线索，不断言相关工作从未开展。

## 论文与当前文件的关系

[论文展示版 PDF](../01_Academic/01_Thesis/Final/Dissertation_LIU%20Zhaolin.pdf) 第 4–7 章和 [答辩 PDF](../01_Academic/03_Defense/Final/final%20report.pdf) 是主要工程叙述来源。论文的独立相机/深度实验描述与当前活动标定文件不完全相同，当前复现以冻结配置和哈希核对结果为准。

论文封面的学号已从展示 PDF 移除，技术正文未改；原始可编辑论文不包含在此展示版本。旧版本的技术局限已汇入 [验证状态](VALIDATION_STATUS.md)。

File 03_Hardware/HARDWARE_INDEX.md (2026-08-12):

# Hardware Asset Index

## Completed hardware collection

- 13 native SolidWorks files: 12 parts and one LED-board assembly.
- Nine STL files: seven custom/calibration/connection parts and two gripper parts.
- Three acrylic-mould DXF drawings.
- Project master BOM with 38 procurement/material rows.
- LED PCB electronics BOM with four component rows.
- EasyEDA Pro PCB source, Gerber/drill archive, and 11-row pick-and-place workbook.
- Twenty-four cataloged project images covering completed sensors, electronics, fixtures, moulding, assembly, and manufacturing.
- Manufacturing and assembly notes covering silicone preparation, mould sealing, casting, curing, and vacuum degassing.

## Native CAD

- SolidWorks sources: `01_CAD_Source/`
- Custom/calibration/connection STL files: `03_Print_Files_STL/Converted/SolidWorks_Parts/`
- Existing gripper STL files: `03_Print_Files_STL/Existing_Source/Gripper/`
- STL-to-SolidWorks mapping and structural checks: `03_Print_Files_STL/STL_SOURCE_MAPPING.csv`
- Acrylic-mould drawings: `04_Engineering_Drawings/Acrylic_Mold/`

All seven supplied custom STL files pass binary structure, finite-coordinate, non-degenerate, single-component, and closed 2-manifold checks. STL files do not encode units, so manufacturing scale and tolerances should be confirmed against the native CAD before printing.

## BOM and electronics

- Project BOM: `05_BOM/Mechanical/Project_Master_BOM.xlsx`
- Electronics BOM: `05_BOM/Electronics/BOM_LED-PCB.xlsx`
- BOM summary: `BOM_INDEX.md`
- EasyEDA project: `07_PCB_and_Electronics/LED_PCB/Source_Project/9DTact_LED_ProEAD.epro`
- Gerber/drill data: `07_PCB_and_Electronics/LED_PCB/Gerber/`
- Pick-and-place: `07_PCB_and_Electronics/LED_PCB/Assembly_Data/PickAndPlace_LED-PCB.xlsx`
- Electronics index: `07_PCB_and_Electronics/ELECTRONICS_INDEX.md`

## Photographs and manufacturing record

- Photo catalog: `08_Renders_and_Photos/PHOTO_CATALOG.md`
- Photo source mapping: `08_Renders_and_Photos/PHOTO_SOURCE_MAPPING.csv`
- Completed dual sensors: `08_Renders_and_Photos/Completed_Hardware/completed_dual_custom_sensors.jpg`
- Sensor exploded view: `08_Renders_and_Photos/Assembly_and_Design/sensor_exploded_view_annotated.jpg`
- FT300 and benchtop fixtures: `08_Renders_and_Photos/Test_Setups/`
- LED PCB/camera photographs: `07_PCB_and_Electronics/Photos/`
- Process photographs: `09_Manufacturing_Notes/Process_Photos/`
- Assembly/manufacturing notes: `09_Manufacturing_Notes/ASSEMBLY_AND_MANUFACTURING_NOTES.md`

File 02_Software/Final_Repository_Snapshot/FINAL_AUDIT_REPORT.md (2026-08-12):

# Final Static Audit Report

## Release identity

- Project: **9DTact + FT300 Custom Sensor Project**
- Release branch: `submission/final-sensor-code`
- Protected Git baseline: `0b8d18ac47ef4eb7bf116efac63c2eee5e83aded` from `experiment/7.25-original-depth-lut`
- Ubuntu source archive used for hardware-facing settings: `7.25修改.zip`
- Review date: 2026-08-11
- Intended platform: Ubuntu 20.04, Python 3.8, and ROS Noetic

The interrupted local work was preserved outside the repository before this branch was created. Its complete status, working and cached diffs, untracked-file list, copied untracked files, and a local-only WIP commit are retained in `<EXTERNAL_WIP_BACKUP>`. That backup is not part of this submission.

## Scope completed

This release provides the repository structure and documented workflow for:

1. dependency installation and static environment verification;
2. independent Sensor 1 and Sensor 2 configuration selection;
3. camera calibration, including the Ubuntu-exported `manual_camera_calibration_v2.py` workflow;
4. sensor/depth calibration and 3D Shape Reconstruction;
5. Robotiq FT300 six-axis ground-truth acquisition through a configurable `geometry_msgs/WrenchStamped` topic;
6. synchronized tactile-image and FT300 collection;
7. object-disjoint dataset splitting, normalization, and integrity checks;
8. ResNet18 smoke training and DenseNet169 full training entry points;
9. normalized prediction and physical wrench prediction in N and N*m;
10. a ROS Noetic catkin package with sensor, shape, acquisition, force, combined-demo, and comparison launches.

The trained tactile model produces its prediction from a 9DTact image. The FT300 is used for labels during acquisition and as optional ground truth during comparison; it is not an inference dependency.

## Hardware configuration source and reconciliation

The latest Ubuntu export was used as the highest-priority source for active hardware-facing configuration. Both sensor templates retain:

- `camera_channel: 2`;
- image resolution `640 x 480`;
- camera crop `[280, 380]`.

The exported force templates still contained the earlier `[345, 460]` image size. The final force templates were reconciled to `[280, 380]`, so each sensor's Shape Reconstruction crop and force-training input size now agree. `/dev/videoX` numbering is host-specific and must be checked with `v4l2-ctl` before every hardware session.

## Calibration state and limitations

For both sensors, the active camera arrays passed the required shape checks:

| File | Shape | SHA-256 |
| --- | --- | --- |
| `row_index.npy` | `(480, 640)` | `f54090298f15e1e706256368d4b3e4308eecae751d241664b082fd61abf8c9aa` |
| `col_index.npy` | `(480, 640)` | `f3f22ccf78d15431d178ac6fabb66b44c5a390b3354fb8f485f2533f05737982` |
| `position_scale.npy` | `(3,)` | `15c95bf85f6da828832e20ee64da0d195427f11f96918b1795b6a3288326c118` |

The three core camera arrays are byte-identical between Sensor 1 and Sensor 2. Sensor 2 includes manual-point provenance; the supplied Ubuntu material does not contain an independent Sensor 1 point set or report and identifies its calibration as reused. This release preserves that evidence and does not claim independent camera-calibration provenance for Sensor 1.

The Ubuntu-exported `manual_camera_calibration_v2.py` was preserved byte-for-byte with SHA-256 `0511f4688f6cc5b9e9d721596af9660d736dbc4c6d1e73869ab5df7d861bcf75`. It supports capture or loaded images, 63 row-major points, snapping, undo, preview, save, and regeneration of the three camera arrays.

The experimental hybrid depth configuration remains active:

- official source: `Original/shape_reconstruction/calibration/sensor_1/depth_calibration/Pixel_to_Depth.npy`;
- source shape: `(61,)`;
- source range: `-0.9467841221106313` to `1.9151455666508503`;
- source and both target SHA-256 values: `19c9f3514dce402d8e710079757394b5445b74e7afbdd2459de43798676cb4ff`.

Each sensor retains its active camera-calibration directory while sharing this upstream depth LUT. This is an engineering experiment, not evidence of an independent and accurate depth calibration for either custom sensor.

## FT300 and legacy isolation

The supported collector is `custom_9dtact/data_collection/collect_data_ft300.py`. It accepts a parameterized external `WrenchStamped` topic, performs finite/freshness/frame checks, software zeroing, configurable axis signs and wrench transformation, approximate image/wrench synchronization, and atomic sensor-specific sample writes.

The upstream BOTA/Rokubi Mini collector was moved out of the active workflow to `custom_9dtact/legacy/bota/collect_data_bota_legacy.py`. A scan of operational code found zero active references to `rokubimini_msgs`, BOTA, MiniONE, `/bus0/ft_sensor0`, or `ft_sensor0`. The immutable `Original/` snapshot and the explicit legacy archive are excluded from that operational scan.

## ROS package

The catkin package is stored at `custom_9dtact/ros_ws/src/9dtact_ft300_ros` and declares the package name `nine_dtact_ft300_ros`. It contains exactly these six release launch files:

- `sensor1_shape.launch`
- `sensor2_shape.launch`
- `ft300_collection.launch`
- `force_estimation.launch`
- `shape_force_demo.launch`
- `compare_prediction_with_ft300.launch`

An external laboratory FT300 driver must first publish `geometry_msgs/WrenchStamped`; its topic is supplied as a launch argument. Physical predictions use `/predicted_wrench` with N and N*m, while optional normalized values use `/predicted_wrench_normalized` and are never labelled as physical units.

## Static verification evidence

The following checks passed on Windows without accessing hardware:

- 30/30 offline unit and source-contract tests;
- Python 3.8 grammar parsing: 85 Python files;
- `compileall`: exit code 0;
- YAML parsing: 9 files;
- ROS package/launch XML parsing: 7 files;
- installation verifier in static-only mode;
- hybrid calibration verifier for both sensors;
- Sensor 1 and Sensor 2 activation/setup static checks;
- sensor-specific configuration isolation;
- Shape Reconstruction crop and force-model image-size agreement at `[280, 380]`;
- six required camera-calibration NumPy shapes;
- both active depth LUT hashes equal the selected official source;
- active BOTA/Rokubi dependency scan: zero hits;
- local user-path scan: zero hits;
- protected `Original/` manifest: 138/138 files identical in path, size, and SHA-256;
- calibration NumPy files are not ignored by Git;
- no dataset, model, runtime, cache, log, or temporary artifact is tracked for delivery;
- `git diff --check` passed.

`SUBMISSION_MANIFEST.csv` records the relative path, byte size, and SHA-256 of every delivered file except the manifest itself, which is excluded to avoid a recursive self-hash.

## Tests deliberately not claimed

Windows static verification does not establish real hardware behavior. This audit did not start or validate:

- a camera or its current `/dev/videoX` assignment;
- ROS Master or an external Robotiq FT300 driver;
- FT300 rate, sign, frame transform, software zero, load accuracy, or synchronization under physical contact;
- CUDA execution;
- live 3D Shape Reconstruction;
- model training or checkpoint quality;
- real-time tactile-only physical wrench prediction;
- prediction-versus-FT300 accuracy.

The complete Ubuntu commands and acceptance checks are documented in `README.md` and `docs/01_INSTALLATION_UBUNTU20.md` through `docs/12_TROUBLESHOOTING.md`. The release should be considered for merge only after both sensors complete the documented Ubuntu hardware checks.

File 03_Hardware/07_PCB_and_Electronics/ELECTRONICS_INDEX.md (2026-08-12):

# PCB and Electronics Index

## Retained engineering assets

| Asset | Path | Contents |
|---|---|---|
| EasyEDA Pro project | `LED_PCB/Source_Project/9DTact_LED_ProEAD.epro` | Schematic and PCB source archive |
| Gerber and drill set | `LED_PCB/Gerber/` | Copper, solder-mask, silkscreen, outline, and drill files |
| Original Gerber ZIP | `LED_PCB/Gerber_Archive/Gerber_LED-PCB_.zip` | Manufacturing archive |
| Electronics BOM | `../05_BOM/Electronics/BOM_LED-PCB.xlsx` | Four component rows |
| Pick-and-place | `LED_PCB/Assembly_Data/PickAndPlace_LED-PCB.xlsx` | Eleven placement rows |
| Hardware photographs | `Photos/` | LED PCB and camera/illumination assemblies |

## System integration

The custom sensor combines the OV5640 USB camera/decoder, LED illumination PCB, optical/acrylic components, and multilayer elastomer structure. The Robotiq FT300 is mounted in the test setup as the six-axis force/torque label and comparison device. The Ubuntu software consumes a parameterized `geometry_msgs/WrenchStamped` topic from the laboratory FT300 driver.

Before powering or rewiring hardware, verify voltage, current, polarity, connector orientation, and current limiting against the actual laboratory assembly and component documentation.

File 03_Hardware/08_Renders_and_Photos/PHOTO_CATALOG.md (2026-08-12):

# Project Photo Catalog

The 24 project images below were imported byte-for-byte from the author's dissertation image source folder. English delivery filenames are used while `PHOTO_SOURCE_MAPPING.csv` preserves each original filename and SHA-256. Together they document the system architecture, electronics, fabrication, calibration, fixtures, completed sensors, and Shape Reconstruction result.

| Final file | Category | Priority | Description |
|---|---|---|---|
| `03_Hardware/08_Renders_and_Photos/Technical_Diagrams/9dtact_system_architecture.png` | Technical_Diagram | Supporting | 9DTact processing and force-estimation architecture diagram. |
| `03_Hardware/07_PCB_and_Electronics/Photos/led_pcb_and_camera.jpg` | Electronics_Photo | Key | LED PCB and camera illumination hardware close-up. |
| `03_Hardware/08_Renders_and_Photos/Technical_Diagrams/three_layer_silicone_concept.png` | Technical_Diagram | Key | Three-layer silicone optical and deformation concept diagram. |
| `03_Hardware/08_Renders_and_Photos/Technical_Diagrams/sensor_optical_structure.png` | Technical_Diagram | Key | Custom tactile sensor optical structure and image formation diagram. |
| `03_Hardware/07_PCB_and_Electronics/Photos/sensor_electronics_components.jpg` | Electronics_Photo | Key | OV5640-style camera module, LED PCB and USB interface board. |
| `03_Hardware/08_Renders_and_Photos/Test_Setups/sensor_ft300_calibration_fixture.jpg` | FT300_Test_Setup | Key | Custom tactile sensor mounted on the FT300 mechanical test structure. |
| `03_Hardware/09_Manufacturing_Notes/Process_Photos/mold_hot_glue_sealing.jpg` | Manufacturing_Process | Supporting | Injection-mold perimeter sealing with hot glue before silicone casting. |
| `03_Hardware/09_Manufacturing_Notes/Process_Photos/multi_layer_casting_molds.jpg` | Manufacturing_Process | Key | Two assembled multi-layer silicone casting molds. |
| `03_Hardware/09_Manufacturing_Notes/Process_Photos/printed_mold_and_housing_parts.jpg` | Manufacturing_Process | Supporting | Collection of 3D-printed mold and housing components. |
| `03_Hardware/08_Renders_and_Photos/Completed_Hardware/completed_dual_custom_sensors.jpg` | Completed_Hardware | Key | Two completed custom tactile sensors with camera cables. |
| `04_Data_and_Models/03_Processed_Data/Shape_Reconstruction_Results/shape_reconstruction_result.png` | Shape_Reconstruction_Result | Key | Ubuntu GUI screenshot showing a 3D shape-reconstruction result. |
| `03_Hardware/09_Manufacturing_Notes/Process_Photos/transparent_g50_bottom_layer.jpg` | Manufacturing_Process | Supporting | Transparent G50 bottom silicone layer after curing. |
| `03_Hardware/08_Renders_and_Photos/Test_Setups/benchtop_sensor_test_fixture.jpg` | Test_Setup | Key | Benchtop tactile-sensor test fixture with camera and cabling. |
| `04_Data_and_Models/02_Calibration_Data/Documentation_Images/Depth_Calibration/depth_calibration_4mm_radius_indenter.jpg` | Depth_Calibration | Supporting | 4 mm radius spherical indenter used for depth calibration. |
| `04_Data_and_Models/02_Calibration_Data/Documentation_Images/Depth_Calibration/depth_calibration_process.png` | Depth_Calibration | Key | Ubuntu depth-calibration process screenshot with contact image. |
| `04_Data_and_Models/02_Calibration_Data/Documentation_Images/Camera_Calibration/camera_calibration_7x9_board.jpg` | Camera_Calibration | Key | Physical 7 by 9 calibration target used for camera mapping. |
| `04_Data_and_Models/02_Calibration_Data/Documentation_Images/Camera_Calibration/manual_camera_calibration_63_point_gui.png` | Camera_Calibration | Key | Manual camera calibration GUI with 63-point grid and preview. |
| `03_Hardware/09_Manufacturing_Notes/Process_Photos/translucent_g5_middle_layer.jpg` | Manufacturing_Process | Supporting | Translucent G5 middle silicone layer after curing. |
| `03_Hardware/09_Manufacturing_Notes/Process_Photos/black_g25_top_layer.jpg` | Manufacturing_Process | Supporting | Black G25 top silicone layer after curing. |
| `03_Hardware/09_Manufacturing_Notes/Process_Photos/silicone_material_preparation.jpg` | Manufacturing_Process | Supporting | Silicone component preparation and manual mixing. |
| `03_Hardware/09_Manufacturing_Notes/Process_Photos/silicone_vacuum_degassing.jpg` | Manufacturing_Process | Key | Vacuum degassing apparatus and silicone cup. |
| `03_Hardware/08_Renders_and_Photos/Assembly_and_Design/sensor_exploded_view_annotated.jpg` | Assembly_Render | Key | Numbered exploded view of the tactile sensor assembly. |
| `03_Hardware/08_Renders_and_Photos/Assembly_and_Design/custom_gripper_assembly_render.png` | Gripper_Render | Key | CAD rendering of the proposed custom gripper integration. |
| `03_Hardware/08_Renders_and_Photos/Test_Setups/screw_loading_sensor_test.jpg` | Assembly_Test | Supporting | Mechanical screw loading on the assembled tactile sensor. |

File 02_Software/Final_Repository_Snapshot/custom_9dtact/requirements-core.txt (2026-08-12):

# Core camera calibration and 3D shape reconstruction dependencies.
# Target platform: Ubuntu 20.04, Python 3.8.
ml-collections==0.1.1
numpy==1.23.5
open3d==0.13.0
opencv-python==4.8.0.76
PyYAML==6.0.1
scipy==1.10.1
setuptools==68.0.0

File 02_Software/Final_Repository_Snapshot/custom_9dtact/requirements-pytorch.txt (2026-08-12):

# These versions support Python 3.8 and are compatible with each other.
# Select the CPU or CUDA wheel index at installation time; see
# ../docs/01_INSTALLATION_UBUNTU20.md.
torch==2.0.1
torchvision==0.15.2

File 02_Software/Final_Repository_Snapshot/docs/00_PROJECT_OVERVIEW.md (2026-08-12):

# 00 - Project Overview

[Home](../README.md) | [Next: Ubuntu installation](01_INSTALLATION_UBUNTU20.md)

## Purpose

This project implements a complete experimental workflow for two custom 9DTact-style
optical tactile sensors and an FT300 six-axis force/torque reference sensor. It keeps
the two tactile devices isolated while providing a common, repeatable sequence from
camera setup to 3D shape reconstruction and learned force estimation.

The intended execution platform is Ubuntu 20.04 with Python 3.8 and ROS Noetic. A
Windows computer can inspect, package, and run offline static checks, but it is not the
hardware-validation platform.

## End-to-end workflow

1. Install the core Python environment and ROS dependencies.
2. Identify the tactile camera device on the current Ubuntu host.
3. Select Sensor 1 or Sensor 2 and run its static setup check.
4. Validate or rebuild that sensor's camera calibration.
5. Decide whether to retain the hybrid official depth LUT or create a new sensor LUT.
6. Validate standalone 3D shape reconstruction on the physical sensor.
7. Start an external FT300 driver and verify its `WrenchStamped` topic.
8. Collect synchronized tactile images and FT300 wrench labels.
9. Check, normalize, and split the per-sensor dataset.
10. Run a short ResNet18 training smoke test, then a full DenseNet169 experiment.
11. Evaluate tactile-only force inference with a sensor-specific checkpoint.
12. Build and use the ROS package for acquisition, reconstruction, inference, or
    prediction-versus-FT300 comparison.

Do not skip directly to training or ROS inference. Each stage depends on evidence from
the previous stage.

## Sensor isolation

| Resource | Sensor 1 | Sensor 2 |
|---|---|---|
| Shape template | `custom_9dtact/configs/shape_sensor_1.yaml` | `custom_9dtact/configs/shape_sensor_2.yaml` |
| Force template | `custom_9dtact/configs/force_sensor_1.yaml` | `custom_9dtact/configs/force_sensor_2.yaml` |
| Calibration | `.../calibration/sensor_1/` | `.../calibration/sensor_2/` |
| Dataset | `custom_9dtact/Dataset_sensor_1/` | `custom_9dtact/Dataset_sensor_2/` |
| Models | `custom_9dtact/saved_models_sensor_1/` | `custom_9dtact/saved_models_sensor_2/` |

Only one sensor is active at a time. `tools/activate_sensor.py` copies the selected
templates to the active configuration paths and records a local marker under
`.runtime/`. It does not copy calibration arrays between sensors.

## Roles of the two sensing systems

### 9DTact-style optical tactile sensor

The camera observes elastomer deformation. Camera calibration maps the raw image to a
rectified physical grid. A depth LUT converts intensity change to a depth estimate for
3D reconstruction. A neural model can also regress six-axis force/torque from tactile
images after supervised training.

### FT300

The FT300 provides physical ground-truth wrench labels during data acquisition and a
reference during validation. It is not an input to normal trained tactile inference.
The repository expects an external ROS driver to publish
`geometry_msgs/WrenchStamped`; the driver itself is not bundled.

## Current calibration evidence

- Active camera-calibration arrays exist for both sensors.
- Sensor 2 includes manual-point provenance artifacts.
- Sensor 1 active arrays do not include independent source artifacts that reproduce
  their manual point selection.
- Both active depth LUTs match the selected upstream Sensor 1 LUT by SHA-256.
- This shared LUT is an experimental hybrid configuration. It has not been shown to be
  an independently accurate depth calibration for either custom sensor.

## Dimensions and device mapping

- Raw camera resolution: `640 x 480` pixels.
- Reconstruction crop: `280 x 380` pixels, height x width, for both sensors.
- Force-model `img_size`: `280 x 380`, aligned to the crop.
- Latest archived camera channel: `2` for both sensor templates.
- `/dev/videoX` numbering: host-specific; check it before each setup or reconnection.

## What is and is not shipped

Included:

- Source code, configurations, calibration arrays, documentation, ROS package, and
  offline validation tools.

Excluded:

- Raw datasets, trained model weights, local runtime state, caches, logs, generated
  bundles, virtual environments, and the external FT300 hardware driver.

## Completion criteria

The graduation-project software package is structurally complete when the offline
submission verifier passes. The experimental system is hardware-validated only after
both sensors separately pass camera, shape, acquisition, training/inference, and ROS
tests on Ubuntu. Record all settings, model checkpoints, topic names, coordinate
transforms, and test results rather than replacing pending evidence with assumptions.

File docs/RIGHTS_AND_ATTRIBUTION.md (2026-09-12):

# 许可与素材来源

[返回首页](../README.md)

本仓库用于工程成果展示。公开可读不自动赋予全部材料商业使用、改编或再分发许可；已有明确许可的资产继续按其原条款使用。

| 资产范围 | 来源与适用范围 |
|---|---|
| 冻结软件与 `Original/` | 保留 [软件 LICENSE](../02_Software/Final_Repository_Snapshot/LICENSE)、[NOTICE](../02_Software/Final_Repository_Snapshot/NOTICE.md) 和 [Original/LICENSE](../02_Software/Final_Repository_Snapshot/Original/LICENSE)。不修改原作者声明，不将其扩展为外层全部资料的统一许可 |
| 上游设计及其外层副本 | 通过 [HARDWARE_PROVENANCE](HARDWARE_PROVENANCE.csv) 识别精确匹配；保留上游来源及已有适用许可，不以复制位置改变原有权利 |
| 本项目定制 CAD、制造与实验照片、展示文档 | 用于查看个人工程工作；本次未另行授予统一开源或商业使用许可。涉及合作或机构权利时，进一步使用须与相应权利人确认 |
| PCB 与厂商器件资料 | PCB 源工程、Gerber ZIP、BOM 与贴片坐标具有上游复用关系。厂商标识属于相应权利人，FT300 手册提供官方链接 |
| 论文和答辩 | 保留必要学术署名与引文；论文展示 PDF 移除学号，技术正文不变。文内第三方图表的引文不等于对其另行授予许可，复用时需回查原来源 |
| 文献全文 | 仅保留 PDF 本身明确声明 CC BY 的 REF_10 和 REF_15，以及官方 9DTact 项目记录及其 LICENSE；其余文献使用书目信息、DOI 与官方链接 |
| 展示图片和视频节选 | 来自现存项目图片与录像，来源、处理和哈希见 [图片映射](assets/IMAGE_SOURCES.json) 与 [视频节选映射](../05_Demos/Previews/PREVIEW_SOURCES.json)。不含本次生成式实物或性能曲线 |

## 上游致谢

9DTact: A Compact Vision-Based Tactile Sensor for Accurate 3D Shape Reconstruction and Generalizable 6D Force Estimation，Changyi Lin、Han Zhang、Jikai Xu、Lei Wu、Huazhe Xu。[上游项目](https://github.com/linchangyi1/9DTact) · [DOI](https://doi.org/10.1109/LRA.2023.3339397)

本项目保留其感知原理、算法与参考工程，个人结构适配、制造和集成见 [贡献说明](PROJECT_OVERVIEW.md)。本次没有给整个资料包添加 MIT 或其他统一许可。

## 保留的开放文献

- Wenzhen Yuan, Siyuan Dong, Edward H. Adelson. *GelSight: High-Resolution Robot Tactile Sensors for Estimating Geometry and Force.* Sensors 17(12), 2762 (2017). [DOI](https://doi.org/10.3390/s17122762)。PDF 明确声明 [CC BY 4.0](https://creativecommons.org/licenses/by/4.0/)，保留完整未修改文件和原署名。
- Benjamin Ward-Cherrier et al. *The TacTip Family: Soft Optical Tactile Sensors with 3D-Printed Biomimetic Morphologies.* Soft Robotics 5(2), 216–227 (2018). [DOI](https://doi.org/10.1089/soro.2017.0052)。所保留出版 PDF 的机构封面标为 CC BY，文中说明允许署名后的分发与复制；保留原许可、署名与未修改文件，具体使用遵循该 PDF 的原声明。

逐项入口见 [文献库](../01_Academic/04_Reference_Library/REFERENCE_LIBRARY_INDEX.md)。源站可下载、开放获取标签和再分发许可是不同事项；尚未明确再分发权利的全文不包含在当前展示版本。

## 阶段报告中的引用媒体

2025 年两轮调研报告改为 [技术摘要与来源入口](../01_Academic/02_Stage_Reports/README.md)，原 PDF/PPTX 中未确认许可的第三方产品图、他人演示及嵌入媒体不随当前版本分发。2026 年 1 月和 2 月展示 PDF 分别省略一处第三方机器人照片及一页厂商产品图，页内注明处理，技术实验记录保留；[映射](../01_Academic/REPORT_DISPLAY_EDITS.csv) 标明修改页和哈希。

保留报告中的 9DTact 原结构图、管线图、混合通道图和论文 Figure 2.1 可与冻结快照 `Original/source/` 下的原作者图像和海报对应。它们是上游关联文档，沿用同目录项目保留的 MIT 许可和作者信息；其原论文中的测试结果不能当成本项目结果。

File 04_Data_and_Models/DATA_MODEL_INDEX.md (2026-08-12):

# Data and Model Asset Index

## Retained project evidence

- `02_Calibration_Data/CALIBRATION_FILE_MANIFEST.csv` inventories active Sensor 1 and Sensor 2 calibration evidence.
- `02_Calibration_Data/Documentation_Images/` contains the calibration board, indenter, depth-calibration process, and manual 63-point camera-calibration images.
- `03_Processed_Data/Shape_Reconstruction_Results/shape_reconstruction_result.png` records the retained Shape Reconstruction result.
- The authoritative calibration arrays and images remain in `02_Software/Final_Repository_Snapshot/custom_9dtact/shape_reconstruction/calibration/`.

## Implemented data workflow

The frozen code contains the complete software structure for:

1. independent Sensor 1 / Sensor 2 dataset roots;
2. synchronized tactile image, mixed image, and FT300 six-axis wrench collection;
3. finite-value and triplet-integrity checking;
4. object-disjoint train/test splitting;
5. wrench normalization and saved normalization metadata;
6. ResNet/DenseNet training;
7. model-associated inference metadata;
8. normalized and physical-unit inference output;
9. ROS prediction and optional FT300 comparison.

Main documentation and entry points are under:

- `02_Software/Final_Repository_Snapshot/docs/07_DATA_COLLECTION.md`
- `02_Software/Final_Repository_Snapshot/docs/08_DATA_PROCESSING.md`
- `02_Software/Final_Repository_Snapshot/docs/09_MODEL_TRAINING.md`
- `02_Software/Final_Repository_Snapshot/docs/10_FORCE_ESTIMATION.md`
- `02_Software/Final_Repository_Snapshot/custom_9dtact/data_collection/`
- `02_Software/Final_Repository_Snapshot/custom_9dtact/force_estimation/`

`DATA_PROTOCOL.md` defines the sample layout, axis order, label units, synchronization method, sensor isolation, collection controls, and integrity checks.

## Upstream reference boundary

Upstream 9DTact reference arrays, images, and examples remain in the immutable software `Original/` snapshot for format and implementation reference. Project-specific calibration evidence is separately identified above.

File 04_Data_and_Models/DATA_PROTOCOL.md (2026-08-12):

# Data Collection Protocol

## Label definition and system boundary

During supervised collection, a custom 9DTact sensor supplies rectified tactile images and the Robotiq FT300 supplies six physical labels: `Fx, Fy, Fz, Tx, Ty, Tz`. Forces use newtons and torques use newton-metres after the documented frame/sign transform. After training, tactile-only inference must not require FT300 input; FT300 remains the ground-truth source for collection and optional validation.

## Sensor isolation

- Sensor 1 dataset root: `Dataset_sensor_1/`
- Sensor 2 dataset root: `Dataset_sensor_2/`
- Never mix sensors, calibration files, normalization metadata, or checkpoints.
- Object IDs are experimental groups; one physical object must not appear in both training and test sets.

## Synchronized sample contract

The collector uses ROS `ApproximateTimeSynchronizer` on the rectified image and a configurable `geometry_msgs/WrenchStamped` topic. Each accepted sample is committed as an atomic triplet:

```text
Dataset_sensor_X/
|-- image/<OBJECT_ID>/<INDEX>.png
|-- mixed_image/<OBJECT_ID>/<INDEX>.png
|-- wrench/<OBJECT_ID>/<INDEX>.npy
`-- acquisition_sessions/<SESSION>.json
```

The wrench label must be a finite six-vector ordered `[Fx, Fy, Fz, Tx, Ty, Tz]`. A common object ID and index identify one sample; never rename one triplet member independently.

## Session record

For every collection session, record the Sensor ID, object/trial ID, calibration and configuration hashes, camera device/settings, FT300 driver/topic/frame/rate, axis/sign/rigid transform, torque origin, unloaded-zero statistics, wrench ranges, synchronization tolerance, save thresholds, operator, host, environment, and observations.

## Collection controls

- Space: start/pause recording
- `n`: next object ID
- `z`: unloaded software zero
- `q`: exit
- Headless services: private `set_recording`, `zero`, and `next_object`

## Checks

Before collection: activate one sensor, verify crop/configuration, inspect the rectified image, check FT300 type/rate/stamp/frame/finite values, and zero only while unloaded. After collection: run `02_Software/Final_Repository_Snapshot/custom_9dtact/tools/check_dataset_integrity.py`, inspect matched triplets, back up the dataset, save normalization metadata, and create object-disjoint splits.

The operational procedures are in `02_Software/Final_Repository_Snapshot/docs/07_DATA_COLLECTION.md` and `02_Software/Final_Repository_Snapshot/docs/08_DATA_PROCESSING.md`.

## Data scope

The project data contract contains tactile images of contact objects and six-axis wrench labels rather than identified human-subject data. Upstream format assets remain separately identified inside the immutable `Original/` snapshot.

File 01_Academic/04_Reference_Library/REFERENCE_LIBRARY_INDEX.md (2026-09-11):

# 参考文献导航

[学术资料](../ACADEMIC_INDEX.md) · [许可说明](COPYRIGHT_AND_ACCESS.md)

33 项书目均保留。全文保留依据是材料自身的再分发声明，而不是公开下载可用性。

| 编号 | 文献 | 来源入口 | 当前全文 |
|---|---|---|---|
| 1 | Intelligence without representation | [DOI/官方来源](https://doi.org/10.1016/0004-3702(91)90053-M) | 仅保留书目与来源链接 |
| 2 | How the Body Shapes the Way We Think: A New View of Intelligence | 见 CSV 书目记录 | 仅保留书目与来源链接 |
| 3 | Trends and challenges in robot manipulation | [DOI/官方来源](https://doi.org/10.1126/science.aat8414) | 仅保留书目与来源链接 |
| 4 | Hands for dexterous manipulation and robust grasping: a difficult road toward simplicity | [DOI/官方来源](https://doi.org/10.1109/70.897777) | 仅保留书目与来源链接 |
| 5 | Tactile Sensing—From Humans to Humanoids | [DOI/官方来源](https://doi.org/10.1109/TRO.2009.2033627) | 仅保留书目与来源链接 |
| 6 | Robotic tactile perception of object properties: A review | [DOI/官方来源](https://doi.org/10.1016/j.mechatronics.2017.11.002) | 仅保留书目与来源链接 |
| 7 | Tactile sensing in dexterous robot hands — Review | [DOI/官方来源](https://doi.org/10.1016/j.robot.2015.07.015) | 仅保留书目与来源链接 |
| 8 | Magnetic Nanocomposite Cilia Tactile Sensor | [DOI/官方来源](https://doi.org/10.1002/adma.201504015) | 仅保留书目与来源链接 |
| 9 | Retrographic sensing for the measurement of surface texture and shape | [DOI/官方来源](https://doi.org/10.1109/CVPR.2009.5206534) | 仅保留书目与来源链接 |
| 10 | GelSight: High-Resolution Robot Tactile Sensors for Estimating Geometry and Force | [DOI/官方来源](https://doi.org/10.3390/s17122762) | [保留 PDF](Files/REF_10_2017_GelSight_High_Resolution_Robot_Tactile_Sensors_for_Estimating_Geometry_and_Force.pdf) · CC BY |
| 11 | Improved GelSight tactile sensor for measuring geometry and slip | [DOI/官方来源](https://doi.org/10.1109/IROS.2017.8202149) | 仅保留书目与来源链接 |
| 12 | GelSlim: A High-Resolution, Compact, Robust, and Calibrated Tactile-sensing Finger | [DOI/官方来源](https://doi.org/10.1109/IROS.2018.8593661) | 仅保留书目与来源链接 |
| 13 | GelSlim 3.0: High-Resolution Measurement of Shape, Force and Slip in a Compact Tactile-Sensing Finger | [DOI/官方来源](https://doi.org/10.1109/ICRA46639.2022.9811832) | 仅保留书目与来源链接 |
| 14 | DIGIT: A Novel Design for a Low-Cost Compact High-Resolution Tactile Sensor With Application to In-Hand Manipulation | [DOI/官方来源](https://doi.org/10.1109/LRA.2020.2977257) | 仅保留书目与来源链接 |
| 15 | The TacTip Family: Soft Optical Tactile Sensors with 3D-Printed Biomimetic Morphologies | [DOI/官方来源](https://doi.org/10.1089/soro.2017.0052) | [保留 PDF](Files/REF_15_2018_The_TacTip_Family_Soft_Optical_Tactile_Sensors_with_3D_Printed_Biomimetic_Morpho.pdf) · CC BY |
| 16 | Combining finger vision and optical tactile sensing: Reducing and handling errors while cutting vegetables | [DOI/官方来源](https://doi.org/10.1109/HUMANOIDS.2016.7803400) | 仅保留书目与来源链接 |
| 17 | ReSkin: Versatile, Replaceable, Lasting Tactile Skins | [DOI/官方来源](https://arxiv.org/pdf/2111.00071) | 仅保留书目与来源链接 |
| 18 | DTact: A Vision-Based Tactile Sensor that Measures High-Resolution 3D Geometry Directly from Darkness | [DOI/官方来源](https://doi.org/10.1109/ICRA48891.2023.10160796) | 仅保留书目与来源链接 |
| 19 | 9DTact: A Compact Vision-Based Tactile Sensor for Accurate 3D Shape Reconstruction and Generalizable 6D Force Estimation | [DOI/官方来源](https://doi.org/10.1109/LRA.2023.3339397) | 仅保留书目与来源链接 |
| 20 | DelTact: A Vision-Based Tactile Sensor Using a Dense Color Pattern | [DOI/官方来源](https://doi.org/10.1109/LRA.2022.3196141) | 仅保留书目与来源链接 |
| 21 | DenseTact 2.0: Optical Tactile Sensor for Shape and Force Reconstruction | [DOI/官方来源](https://doi.org/10.1109/ICRA48891.2023.10161150) | 仅保留书目与来源链接 |
| 22 | Photometric Method For Determining Surface Orientation From Multiple Images | [DOI/官方来源](https://doi.org/10.1117/12.7972479) | 仅保留书目与来源链接 |
| 23 | Dense Tactile Force Estimation using GelSlim and inverse FEM | [DOI/官方来源](https://doi.org/10.1109/ICRA.2019.8794113) | 仅保留书目与来源链接 |
| 24 | Effective Estimation of Contact Force and Torque for Vision-Based Tactile Sensors With Helmholtz–Hodge Decomposition | [DOI/官方来源](https://doi.org/10.1109/LRA.2019.2930477) | 仅保留书目与来源链接 |
| 25 | More Than a Feeling: Learning to Grasp and Regrasp Using Vision and Touch | [DOI/官方来源](https://doi.org/10.1109/LRA.2018.2852779) | 仅保留书目与来源链接 |
| 26 | Maintaining Grasps within Slipping Bounds by Monitoring Incipient Slip | [DOI/官方来源](https://doi.org/10.1109/ICRA.2019.8793538) | 仅保留书目与来源链接 |
| 27 | Slip Detection for Grasp Stabilization With a Multifingered Tactile Robot Hand | [DOI/官方来源](https://doi.org/10.1109/TRO.2020.3031245) | 仅保留书目与来源链接 |
| 28 | Densely Connected Convolutional Networks | [DOI/官方来源](https://doi.org/10.1109/CVPR.2017.243) | 仅保留书目与来源链接 |
| 29 | FT 300 Force Torque Sensor: Instruction Manual | [DOI/官方来源](https://assets.robotiq.com/website-assets/support_documents/document/FT_Sensor_Manual_general_PDF_20190625.pdf) | 仅保留书目与来源链接 |
| 30 | 9DTact: Official Open-Source Hardware, Software, Dataset and Pretrained Models. | [DOI/官方来源](https://github.com/linchangyi1/9DTact) | [上游记录](Files/REF_30_9DTact_Official_Repository/README.md) |
| 31 | Transfer learning for vision-based tactile sensing | [DOI/官方来源](https://doi.org/10.1109/IROS40897.2019.8967571) | 仅保留书目与来源链接 |
| 32 | Deep Domain Adaptation Regression for Force Calibration of Optical Tactile Sensors | [DOI/官方来源](https://doi.org/10.1109/IROS58592.2024.10801904) | 仅保留书目与来源链接 |
| 33 | TransForce: Transferable Force Prediction for Vision-Based Tactile Sensors with Sequential Image Translation | [DOI/官方来源](https://doi.org/10.1109/ICRA55743.2025.11127381) | 仅保留书目与来源链接 |

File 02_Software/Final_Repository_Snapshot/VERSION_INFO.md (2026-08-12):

# Version and Validation Information

## Delivery identity

- Delivery name: 9DTact + FT300 Custom Tactile Sensor Graduation Project
- Documentation date: 2026-08-11
- Source baseline commit: `0b8d18ac47ef4eb7bf116efac63c2eee5e83aded`
- Delivery branch: `submission/final-sensor-code`
- Target platform: Ubuntu 20.04 LTS
- Python baseline: 3.8
- ROS baseline: ROS Noetic

The source baseline identifies the repository state from which the final submission was
assembled. Final delivery changes on the branch are intentionally newer than that
baseline.

## Active sensor configuration facts

| Item | Sensor 1 | Sensor 2 |
|---|---:|---:|
| Archived Ubuntu camera channel | `2` | `2` |
| Camera resolution | `640 x 480` | `640 x 480` |
| Reconstruction crop, height x width | `280 x 380` | `280 x 380` |
| Force-model image size, height x width | `280 x 380` | `280 x 380` |
| Dataset directory | `Dataset_sensor_1` | `Dataset_sensor_2` |
| Model directory | `saved_models_sensor_1` | `saved_models_sensor_2` |

The camera channel records the latest exported Ubuntu configuration, not a portable
device identity. `/dev/videoX` enumeration can change after reconnecting hardware or
moving the repository to another host.

## Hybrid depth-LUT state

Both active custom sensors use this upstream source LUT:

`Original/shape_reconstruction/calibration/sensor_1/depth_calibration/Pixel_to_Depth.npy`

- Array shape: `(61,)`
- Minimum: `-0.9467841221106313`
- Maximum: `1.9151455666508503`
- SHA-256: `19C9F3514DCE402D8E710079757394B5445B74E7AFBDD2459DE43798676CB4FF`

Each sensor retains a sensor-specific active camera path. The current three core camera
arrays are byte-identical between those paths and must not be described as independently
derived. File identity and numerical validity are statically checkable, but the shared
upstream LUT has not been proven to be a precise physical depth calibration for either
custom sensor. Both sensors require separate Ubuntu hardware reconstruction tests.

Running `_2_Sensor_Calibration.py` for an active sensor replaces its
`Pixel_to_Depth.npy` and intentionally exits this hybrid state. Preserve a backup before
that operation. If the official hybrid LUT is restored later, run
`python tools/verify_hybrid_calibration.py` again.

## Camera-calibration provenance

- Sensor 1 active camera arrays are present, but this delivery does not contain
  independent manual-point source artifacts that reproduce their origin.
- Sensor 2 active camera arrays are accompanied by manual-point provenance artifacts.
- Neither statement replaces physical validation of rectification quality on the
  corresponding device.

## Included software layers

- Per-sensor configuration activation and static setup checks
- Automatic and manual camera-calibration workflows
- Hybrid-depth-LUT verification
- Standalone 3D shape reconstruction
- FT300 `WrenchStamped` topic validation and synchronized data collection
- Wrench normalization, dataset integrity checks, and split tools
- ResNet/DenseNet training and six-axis tactile inference
- Per-model `inference_metadata.json` (schema version 1) for sensor identity, input
  size, wrench ranges, frame, axis order, units, and normalization; legacy checkpoints
  require a warned manual-verification fallback that can be disabled in configuration
- ROS Noetic catkin package with six launch workflows
- Offline installation and submission verification scripts

Datasets, trained weights, camera devices, the FT300 hardware driver, ROS installation,
and system-specific virtual environments are not bundled.

## Validation matrix

| Check | Status | Meaning |
|---|---|---|
| Repository structure | Static check available | Required paths can be inspected offline |
| Python 3.8 syntax | Static check available | Source parses against the Python 3.8 grammar |
| YAML and ROS XML | Static check available | Configuration and launch syntax can be parsed |
| Calibration array shapes/finiteness | Static check available | Files are readable and structurally valid |
| Hybrid LUT hash equality | Static check available | Both active LUT files match the selected upstream source |
| Camera acquisition | Pending Ubuntu hardware test | Correct `/dev/videoX`, exposure, focus, and stream must be verified |
| Camera rectification | Pending per-sensor test | Grid geometry and crop must be visually checked |
| Shape reconstruction | Pending per-sensor test | No-contact, press, release, and location response must be recorded |
| FT300 topic and transform | Pending hardware test | Rate, timestamp, frame, sign, zero, and units must be checked |
| Data collection | Pending hardware test | Image/wrench synchronization and saved samples must be checked |
| Training and inference | Pending target-computer test | Requires real datasets, checkpoints, and selected CPU/CUDA stack |
| ROS combined workflow | Pending Ubuntu hardware test | Nodes and topics must be tested together |

## Protected upstream snapshot

`Original/` is a read-only reference snapshot. The final workflow does not edit its
contents. When an external baseline manifest is available, run:

```bash
cd <LOCAL_PROJECT_ROOT>
python scripts/verify_submission.py --original-baseline <ORIGINAL_BASELINE_CSV>
```

## Reproducibility commands

Core environment check:

```bash
cd <LOCAL_PROJECT_ROOT>
python scripts/verify_installation.py --profile core
```

Offline repository check:

```bash
python scripts/verify_submission.py
```

Hybrid LUT check:

```bash
cd custom_9dtact
python tools/verify_hybrid_calibration.py
```

These commands do not start a camera, ROS master, FT300 device, CUDA workload,
Shape Reconstruction, training, or inference unless a later document explicitly tells
the user to start that stage.

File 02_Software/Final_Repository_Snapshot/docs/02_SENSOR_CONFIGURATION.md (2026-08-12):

# 02 - Sensor Configuration

[Previous: Installation](01_INSTALLATION_UBUNTU20.md) | [Home](../README.md) | [Next: Camera calibration](03_CAMERA_CALIBRATION.md)

## Configuration model

Each sensor has two persistent templates:

```text
custom_9dtact/configs/
|-- shape_sensor_1.yaml
|-- shape_sensor_2.yaml
|-- force_sensor_1.yaml
`-- force_sensor_2.yaml
```

Activation copies one sensor's templates to these generated active files:

```text
custom_9dtact/shape_reconstruction/shape_config.yaml
custom_9dtact/force_estimation/force_config.yaml
```

Edit the persistent template, not only the active copy. Re-activate after every
template change so both active files and the `.runtime/active_sensor.txt` marker agree.

## 1. Identify the camera on this host

Connect only the intended tactile camera while mapping devices:

```bash
v4l2-ctl --list-devices
ls -l /dev/video*
```

If necessary, inspect formats without starting the project:

```bash
v4l2-ctl --device=/dev/video2 --list-formats-ext
```

The latest Ubuntu archive records `camera_channel: 2` for both sensors. This is a
historical host mapping, not a permanent camera identity. USB order, capture cards,
and reconnects can change `/dev/videoX` numbering.

Update the selected template if needed:

```yaml
camera_setting:
  camera_channel: 2
  resolution:
    - 640
    - 480
  fps: 30
```

Record how the physical device was identified. A stable udev rule can be used by an
experienced system administrator, but the numeric channel in this project must still
match the OpenCV device opened on that host.

## 2. Confirm geometry alignment

Both selected shape templates use:

```yaml
camera_calibration:
  crop_size:
    - 280
    - 380
```

The corresponding force templates must use:

```yaml
img_size:
  - 280
  - 380
```

The order is height, then width. The submission verifier rejects a mismatch between
`crop_size` and `img_size`.

## 3. Activate one sensor

Sensor 1:

```bash
cd <LOCAL_PROJECT_ROOT>/custom_9dtact
python tools/activate_sensor.py --sensor-id 1
python tools/check_sensor_setup.py --sensor-id 1
```

Sensor 2:

```bash
cd <LOCAL_PROJECT_ROOT>/custom_9dtact
python tools/activate_sensor.py --sensor-id 2
python tools/check_sensor_setup.py --sensor-id 2
```

The activation tool backs up previous active configuration files under
`.runtime/config_backups/` and retains a bounded local history. `.runtime/` is not a
version-controlled source of truth.

Use the stricter data check before training:

```bash
python tools/check_sensor_setup.py --sensor-id 1 --require-data
```

## 4. Keep sensor resources isolated

Sensor 1 must use:

- `shape_reconstruction/calibration/sensor_1/`
- `Dataset_sensor_1/`
- `saved_models_sensor_1/`

Sensor 2 must use:

- `shape_reconstruction/calibration/sensor_2/`
- `Dataset_sensor_2/`
- `saved_models_sensor_2/`

Do not copy one sensor's camera arrays into the other sensor directory. Do not point a
force template at the other sensor's dataset or model directory. If a result appears
only after such a cross-copy, treat it as a configuration error rather than evidence.

## 5. Pre-run checklist

Before opening the camera or running ROS, confirm:

- the physical sensor ID is recorded;
- the matching templates are active;
- the current camera channel is verified on this Ubuntu host;
- crop size and force-model image size are both `280 x 380`;
- calibration paths point to the selected sensor;
- dataset and model paths point to the selected sensor;
- no second sensor process is still running;
- any calibration or data to be modified has an external backup.

Proceed to camera calibration only after this checklist passes.

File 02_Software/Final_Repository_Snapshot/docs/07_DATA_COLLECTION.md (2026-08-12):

# 07 - FT300-Labelled Data Collection

[Previous: FT300 setup](06_FT300_SETUP.md) | [Home](../README.md) | [Next: Data processing](08_DATA_PROCESSING.md)

## Output contract

The collector synchronizes a rectified tactile image with an external FT300
`WrenchStamped` sample using ROS message timestamps. For each object ID it writes a
matched triplet:

```text
Dataset_sensor_X/
|-- image/<OBJECT_ID>/<INDEX>.png
|-- mixed_image/<OBJECT_ID>/<INDEX>.png
|-- wrench/<OBJECT_ID>/<INDEX>.npy
`-- acquisition_sessions/<SESSION>.json
```

The raw wrench array has six finite physical values in the configured tactile frame.
Files with a common object ID and index form one sample. Do not rename one member of a
triplet independently.

## Before each session

- back up the existing `Dataset_sensor_X/` directory;
- activate the correct sensor and pass its setup check;
- validate standalone shape/camera output;
- confirm `crop_size` and force `img_size` are both `280 x 380`;
- verify the external FT300 topic, timestamp, frame, sample rate, zero, and signs;
- review dataset root, object ID, wrench ranges, transform, synchronization tolerance,
  and save thresholds in the launch file;
- place the system in a safe, unloaded state.

## Startup order

1. Start `roscore`.
2. Start the tactile sensor/image publisher.
3. Start the external FT300 driver.
4. Run `tools/check_ft300_topic.py` and correct any message error.
5. Start the FT300 collector with `ft300_collection.launch`.
6. Verify the displayed sensor ID, object ID, wrench, and saved-sample count.
7. Zero only while unloaded.
8. Start recording and apply the planned contacts.

Build and source the workspace first:

```bash
source /opt/ros/noetic/setup.bash
source <LOCAL_PROJECT_ROOT>/custom_9dtact/.venv/bin/activate
cd <LOCAL_PROJECT_ROOT>/custom_9dtact/ros_ws
catkin_make
source devel/setup.bash
```

Start the collector with the declared arguments. Sensor 1 example:

```bash
roslaunch nine_dtact_ft300_ros ft300_collection.launch \
  sensor_id:=1 \
  shape_config:=configs/shape_sensor_1.yaml \
  wrench_topic:=/robotiq_ft_wrench \
  dataset_root:=Dataset_sensor_1 \
  object_id:=1
```

Open `src/9dtact_ft300_ros/launch/ft300_collection.launch` and review every `<arg>`
declaration before changing the example. For Sensor 2, change the sensor ID, shape
configuration, and dataset root together.

## Interactive collector controls

| Key | Action |
|---|---|
| Space | Start or pause recording |
| `n` | Move to the next object ID |
| `z` | Compute a software zero while unloaded |
| `q` | Stop the collector |

In headless mode, use the collector's private `set_recording`, `zero`, and `next_object`
services instead of keyboard controls. Discover the resolved service names with
`rosservice list` after launch.

## Collection design

Use object IDs as experimental groups. Include representative contact locations,
directions, and load levels without exceeding the configured safe range. Avoid long
runs that contain only adjacent frames from one nearly static press.

For every session, preserve:

- sensor and object identity;
- configuration and calibration hashes;
- camera device/channel and capture settings;
- FT300 topic, frame, rate, transform, sign, zero statistics, and wrench ranges;
- synchronization and save thresholds;
- operator, date, host, environmental notes, and anomalies.

## Stop and inspect

1. Press Space to pause.
2. Wait for the saved count to stop changing.
3. Press `q` to stop the collector.
4. Stop image and FT300 publishers, then `roscore`.
5. Back up the dataset before processing.
6. Run an integrity check:

```bash
cd <LOCAL_PROJECT_ROOT>/custom_9dtact
python tools/check_dataset_integrity.py \
  --dataset-root Dataset_sensor_1
```

Inspect several matched image/wrench triplets manually. Confirm that all images are
readable, shape is `280 x 380`, labels are finite six-vectors, and session metadata
matches the intended sensor and transform.

Do not collect Sensor 2 into `Dataset_sensor_1` or continue an object ID under a
different physical object. Correct dataset provenance is part of the experiment, not a
later formatting task.

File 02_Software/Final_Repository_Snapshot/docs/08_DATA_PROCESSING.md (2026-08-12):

# 08 - Dataset Processing

[Previous: Data collection](07_DATA_COLLECTION.md) | [Home](../README.md) | [Next: Model training](09_MODEL_TRAINING.md)

## Processing order

For one sensor at a time:

1. create an external backup;
2. run integrity checks on raw triplets;
3. run wrench normalization in dry-run mode;
4. review configured physical ranges and the report;
5. apply cleaning and normalization only to the intended backup copy or approved
   working dataset;
6. create an object-disjoint train/test split;
7. rerun integrity checks including split indices;
8. freeze a manifest for the training run.

## 1. Check raw dataset integrity

```bash
cd <LOCAL_PROJECT_ROOT>/custom_9dtact
python tools/check_dataset_integrity.py \
  --dataset-root Dataset_sensor_1 \
  --json-report <DATASET_REPORT_JSON>
```

Review missing companions, unreadable arrays, image dimensions, non-finite labels, and
object IDs. Correct acquisition/provenance errors before normalization.

## 2. Review wrench ranges

Activate the sensor so the active force configuration matches the dataset:

```bash
python tools/activate_sensor.py --sensor-id 1
python tools/check_sensor_setup.py --sensor-id 1 --require-data
```

The six-vector ranges in `configs/force_sensor_1.yaml` are physical limits in
`Fx, Fy, Fz, Tx, Ty, Tz` order. Force uses newtons; torque uses newton-metres. Confirm
that the zero, sign convention, transform, and experimental safe range are correct
before using those values to reject samples.

## 3. Dry-run normalization

```bash
cd <LOCAL_PROJECT_ROOT>/custom_9dtact/data_collection
python wrench_normalization.py \
  --dataset-root ../Dataset_sensor_1 \
  --object-num <MAX_OBJECT_ID> \
  --force-config ../configs/force_sensor_1.yaml \
  --dry-run
```

The dry run writes a processing report but does not modify sample triplets. Review:

- valid, incomplete/unreadable, and out-of-range counts;
- files that would be removed;
- normalized files that would be generated;
- the selected configuration and ranges.

## 4. Apply only after backup and review

```bash
python wrench_normalization.py \
  --dataset-root ../Dataset_sensor_1 \
  --object-num <MAX_OBJECT_ID> \
  --force-config ../configs/force_sensor_1.yaml \
  --apply
```

`--apply` can delete incomplete/out-of-range triplets, renumber valid samples within an
object, and rewrite normalized labels. Preserve the dry-run report and external backup.
Never apply the command to the other sensor's dataset by mistake.

## 5. Create an object-disjoint split

Both final split tools separate complete object groups so frames from one physical
object do not appear in both training and test sets. The primary/default generator for
the force templates is `split_train_test_by_object.py`:

```bash
cd <LOCAL_PROJECT_ROOT>/custom_9dtact/data_collection
python split_train_test_by_object.py \
  --dataset-root ../Dataset_sensor_1 \
  --object-number <TOTAL_OBJECT_COUNT> \
  --test-object-number <TEST_OBJECT_COUNT> \
  --seed 42
```

The compatibility generator also performs a randomized object-level split:

```bash
python split_train_test.py \
  --dataset-root ../Dataset_sensor_1 \
  --test-ratio 0.2 \
  --seed 42
```

Record the generator, seed, and test object IDs. Do not present adjacent-frame leakage
as a valid generalization result.

## 6. Final integrity check

```bash
cd <LOCAL_PROJECT_ROOT>/custom_9dtact
python tools/check_dataset_integrity.py \
  --dataset-root Dataset_sensor_1 \
  --require-normalized \
  --check-splits \
  --json-report <FINAL_DATASET_REPORT_JSON>
```

Confirm that training and test object sets are disjoint and that all indexed paths are
portable relative paths inside the selected dataset. Repeat the full procedure for
Sensor 2 with Sensor 2 paths and configuration.

## Optional portable training bundle

Create a per-sensor bundle outside the repository:

```bash
cd <LOCAL_PROJECT_ROOT>
python scripts/create_training_bundle.py \
  --sensor-id 1 \
  --output <EXTERNAL_OUTPUT>/training_bundle_sensor_1.zip
```

The tool validates structure and adds a SHA-256 manifest. It does not run training and
does not include the other sensor's data.

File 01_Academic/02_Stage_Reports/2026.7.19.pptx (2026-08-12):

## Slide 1

HSVmode:HSV

Progress Report

Name: Liu Zhaolin

Date: 19/07/2026

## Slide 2

1.1 Hardware Setup of the Newly Designed Sensor

A completely new design was adopted to minimize the size of the tactile sensor while maximizing its measurement accuracy.

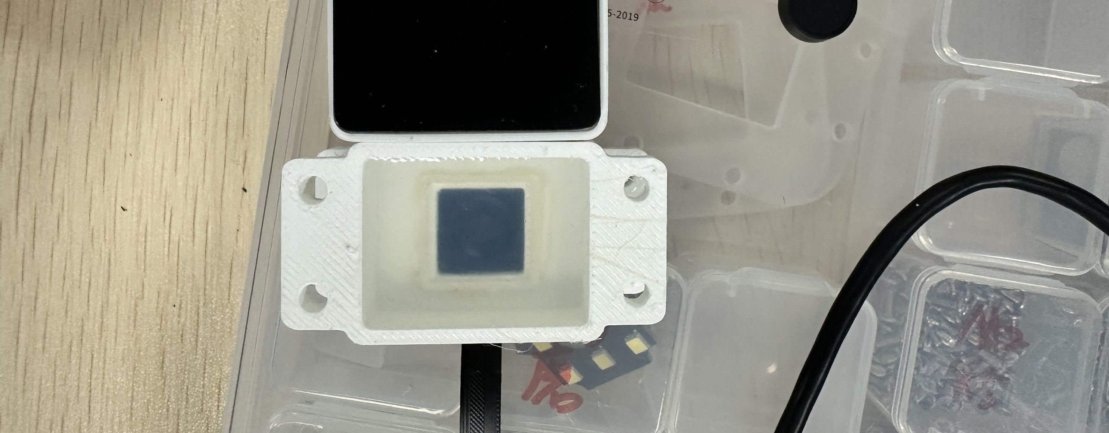
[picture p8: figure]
大小对比1
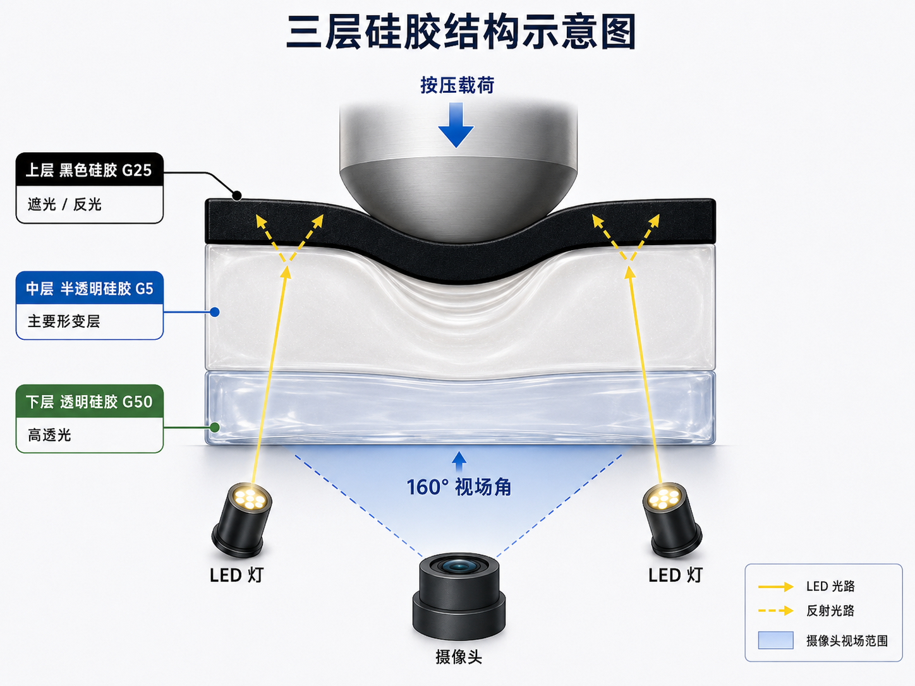
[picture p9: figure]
三层硅胶示意图
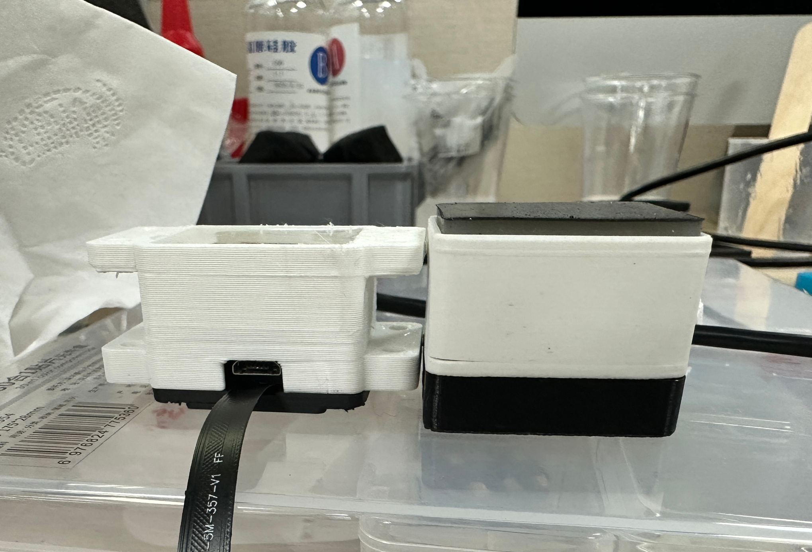
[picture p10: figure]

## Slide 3

1.1 Hardware Setup of the Newly Designed Sensor

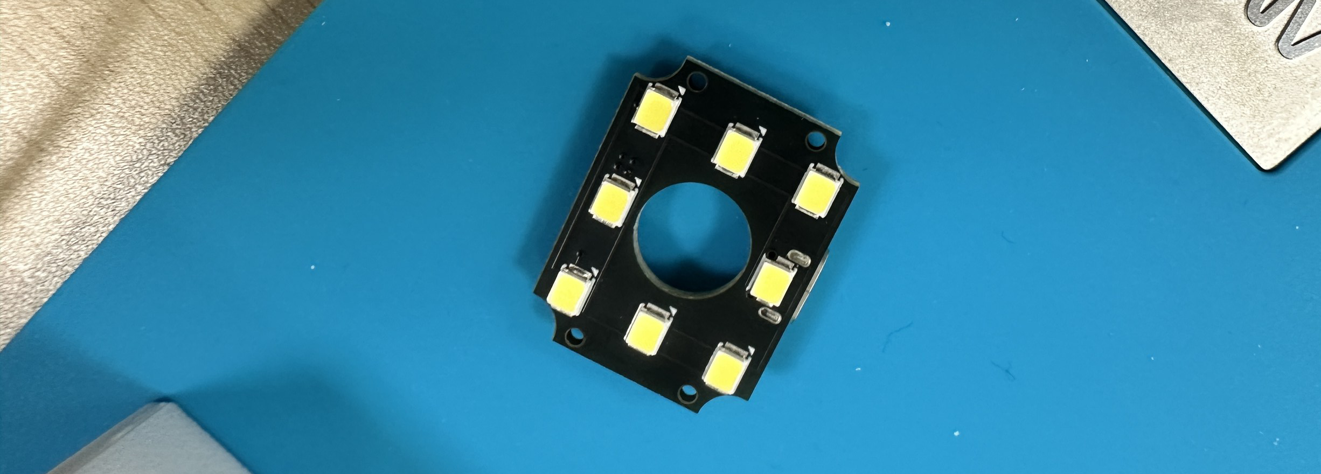
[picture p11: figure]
ledpcb板

Hardware Fabrication Process

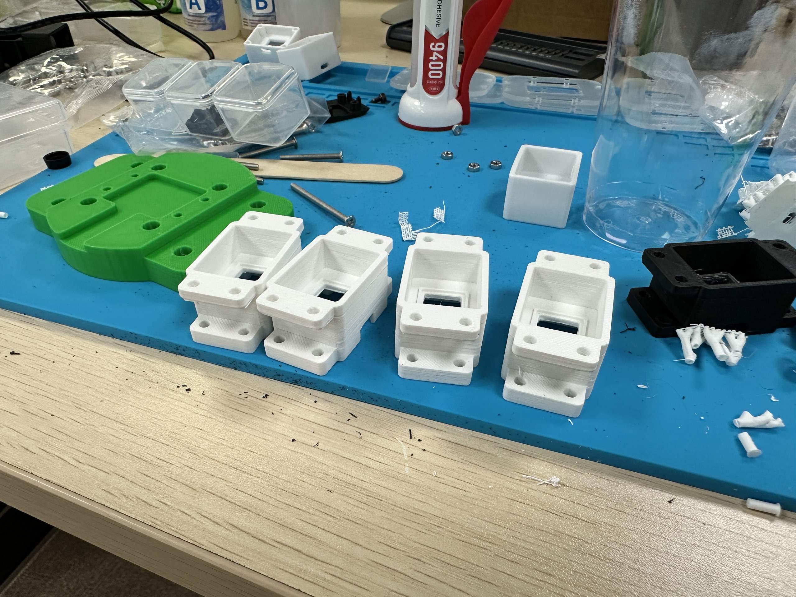
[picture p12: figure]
全新设计的sensor外壳
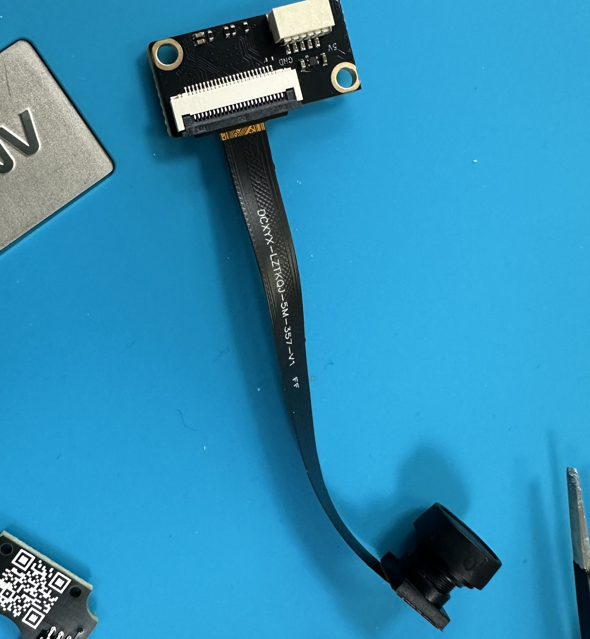
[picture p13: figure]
全新摄像头ov5640

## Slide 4

1.1 Hardware Setup of the Newly Designed Sensor

Hardware Fabrication Process

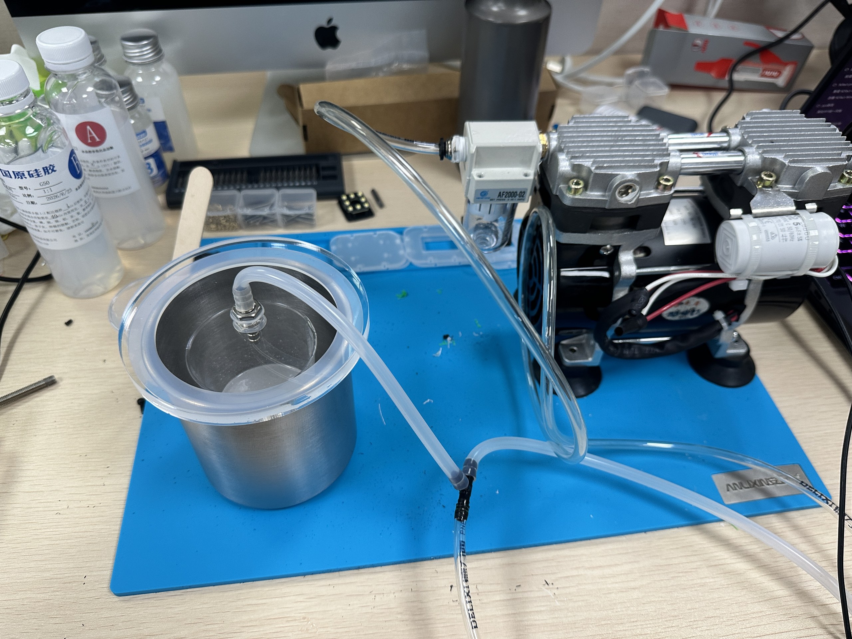
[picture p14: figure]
真空消泡
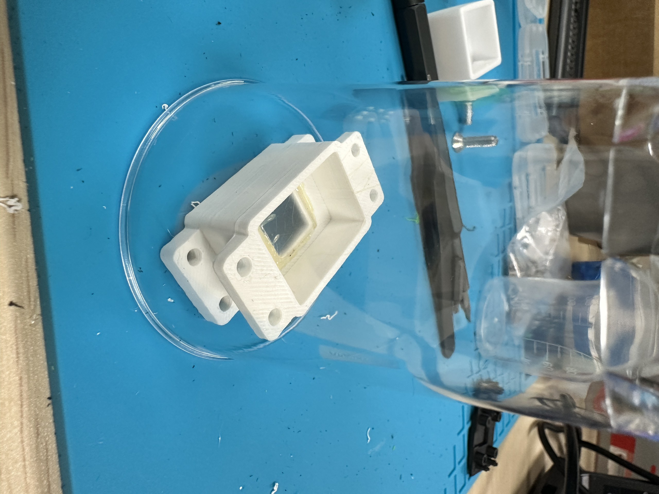
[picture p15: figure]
封窗固化
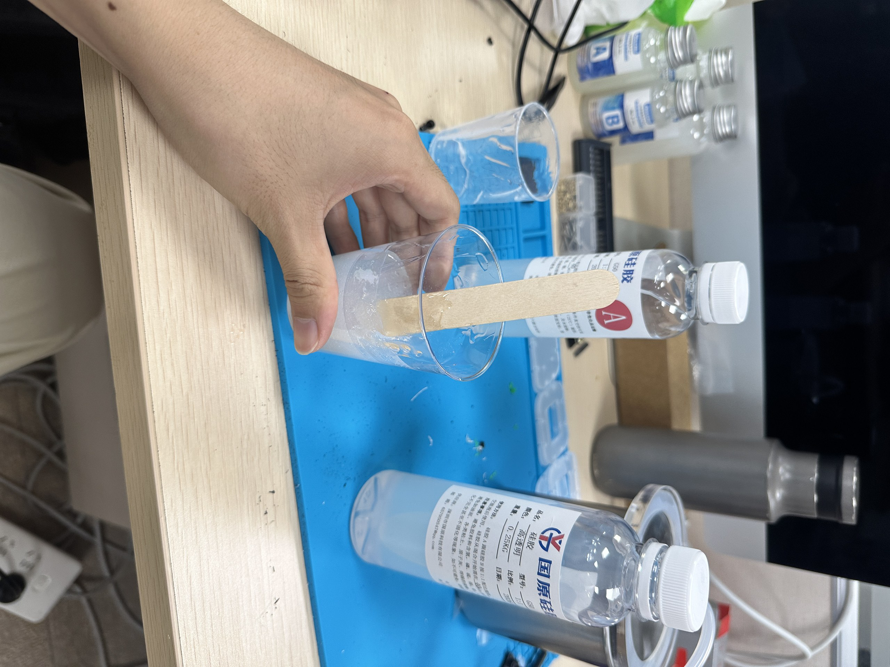
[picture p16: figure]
调硅胶

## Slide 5

1.1 Hardware Setup of the Newly Designed Sensor

Hardware Fabrication Process

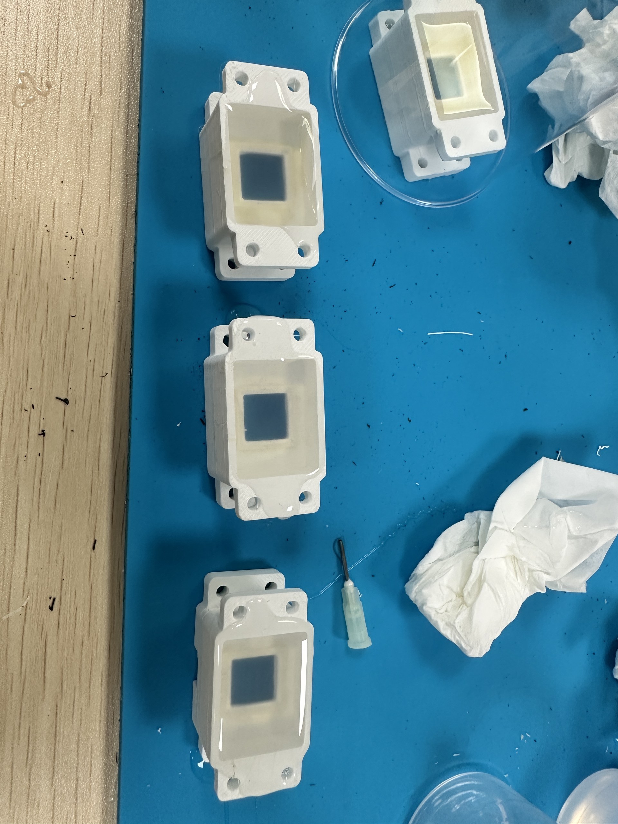
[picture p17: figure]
胶体制作
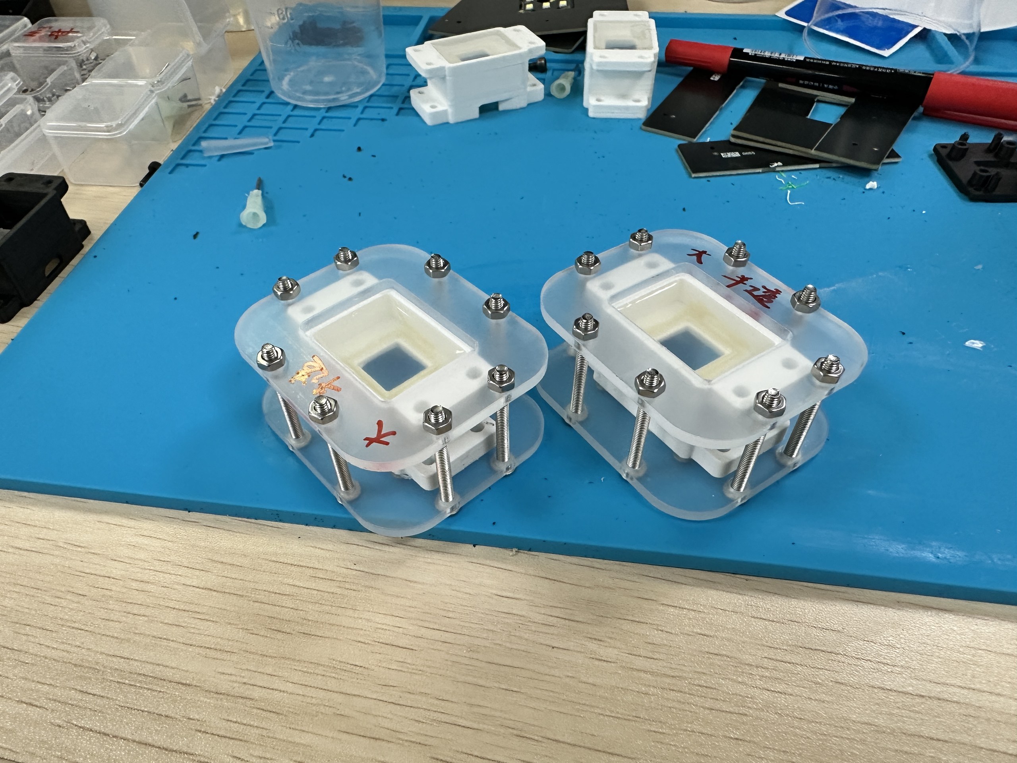
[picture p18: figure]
注胶模具
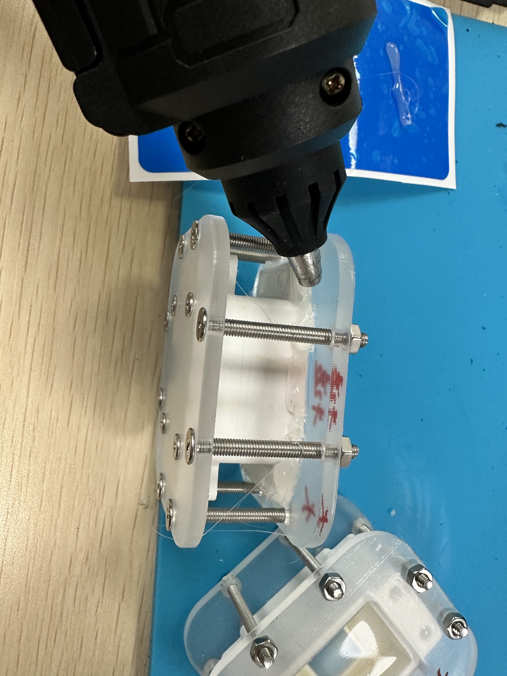
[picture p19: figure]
封模防漏胶

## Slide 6

1.1 Hardware Setup of the Newly Designed Sensor

Electrical Testing

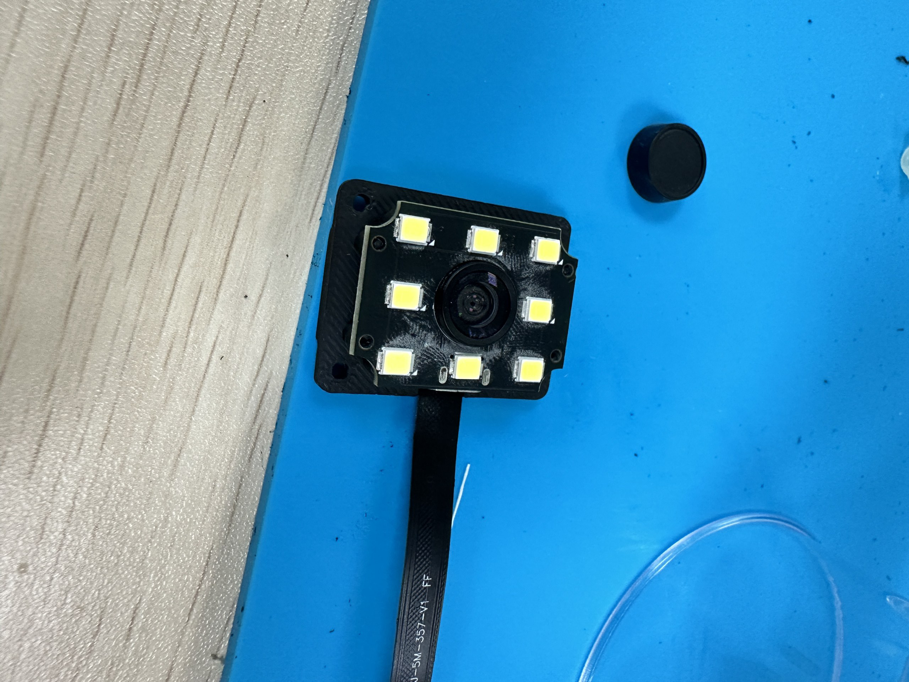
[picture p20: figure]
集成
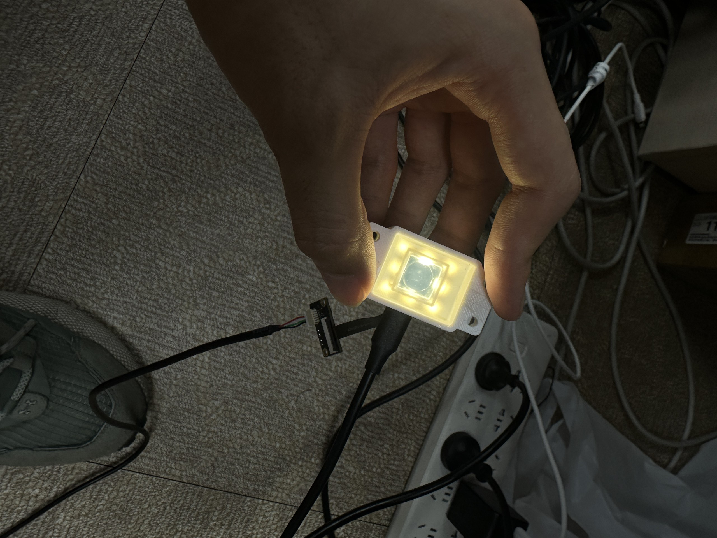
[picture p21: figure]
光路测试

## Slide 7

1.1 Hardware Setup of the Newly Designed Sensor

Six-Axis Force Sensor Setup and Testing

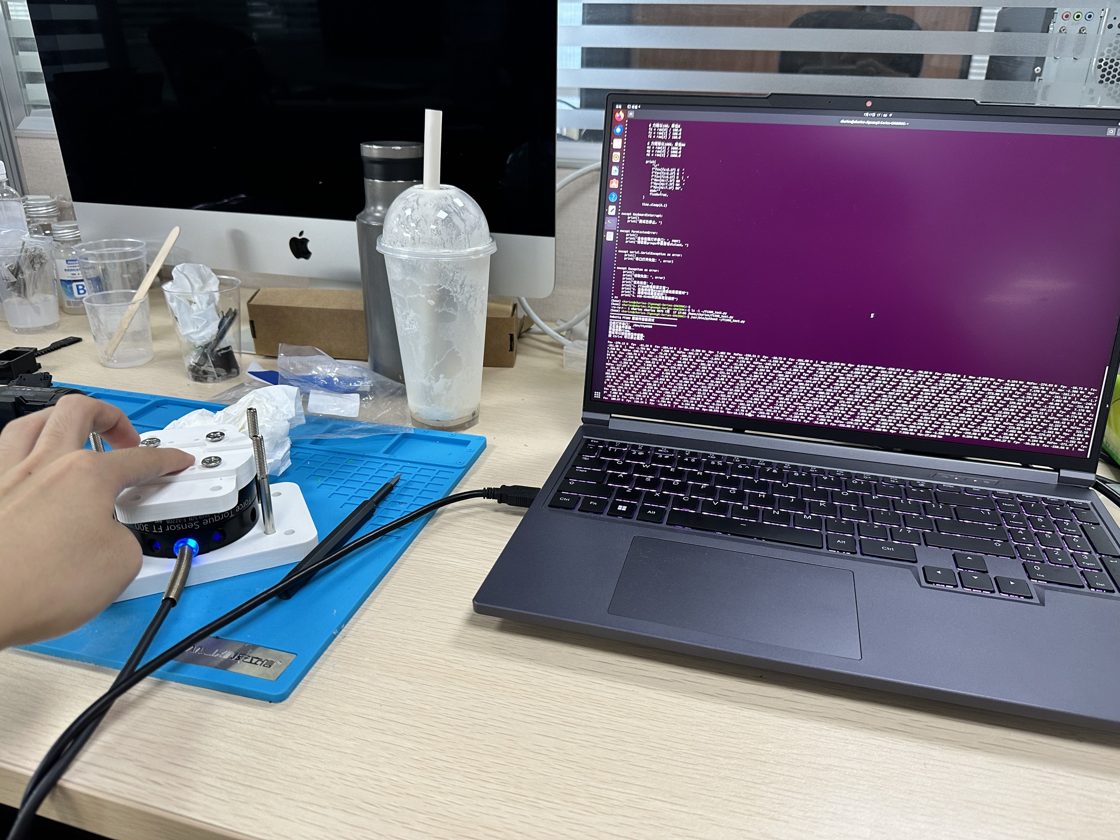
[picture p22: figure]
六维力传感器调试
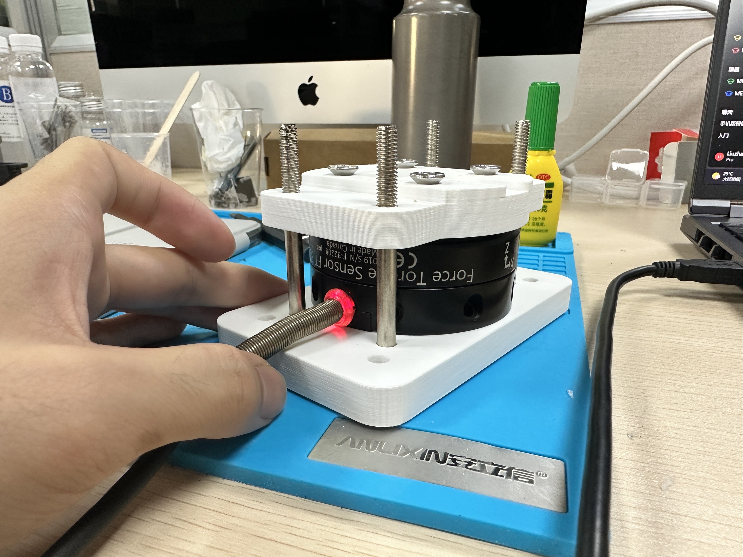
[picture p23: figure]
力矩传感器的标定件连接

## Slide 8

2. Next Week‘s Work Plan

For the hardware：
- Build a synchronized acquisition system for 9DTact images and FT300 six-axis force labels.
- Collect a larger and more diverse dataset, including normal pressing, shear, eccentric loading, and torsion.
- Repeat experiments under different loads, directions, and contact positions to improve data reliability.
- Perform timestamp alignment, outlier removal, and data normalization.
For the software：
- Perform timestamp alignment, outlier removal, and data normalization.
- Train a model to estimate 6Dforces from 9Dtact images.
- Improve estimation accuracy through model tuning and additional data collection.
- Evaluate the model

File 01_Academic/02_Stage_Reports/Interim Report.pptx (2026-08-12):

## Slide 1

HSVmode:HSV

Progress Report
2026 W15 - W16

Name: Liu Zhaolin

Date: 19/04/2026

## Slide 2

CONTENTS

1. Progress Report for the Past Two Weeks

2. Project Plan for the Next Two Months

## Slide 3

1.1 Gripper Design & Tactile Feedback Loop

Aimming to provide a reliable physical validation platform for the application and performance testing of tactile sensors，I designed a robotic gripper.

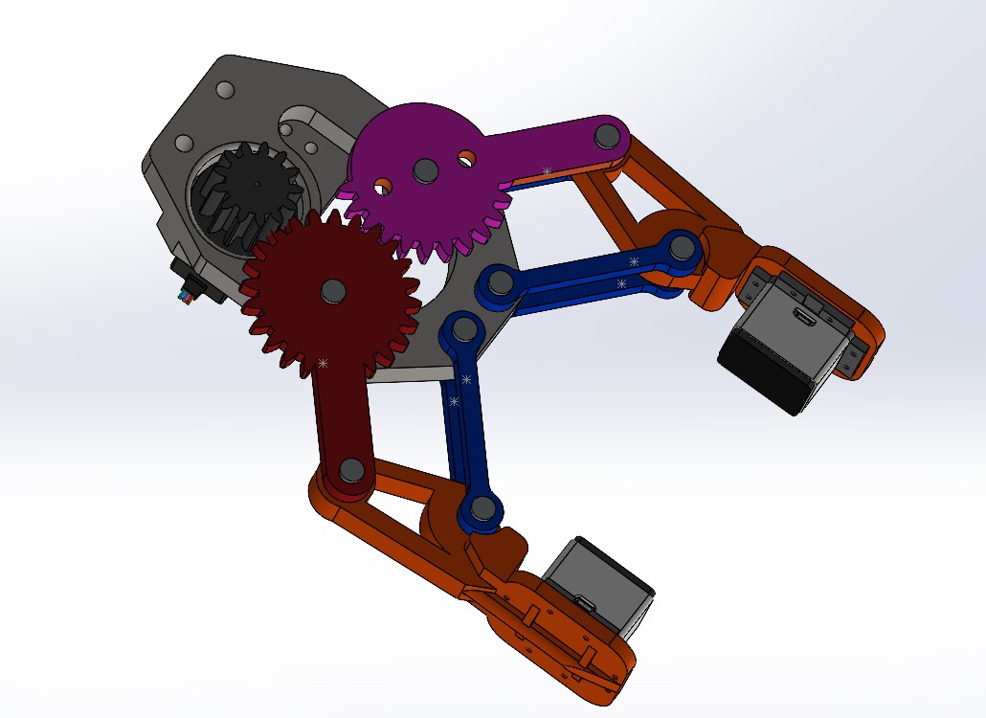
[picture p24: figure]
机械夹爪与传感器配合的全结构照片（背面）
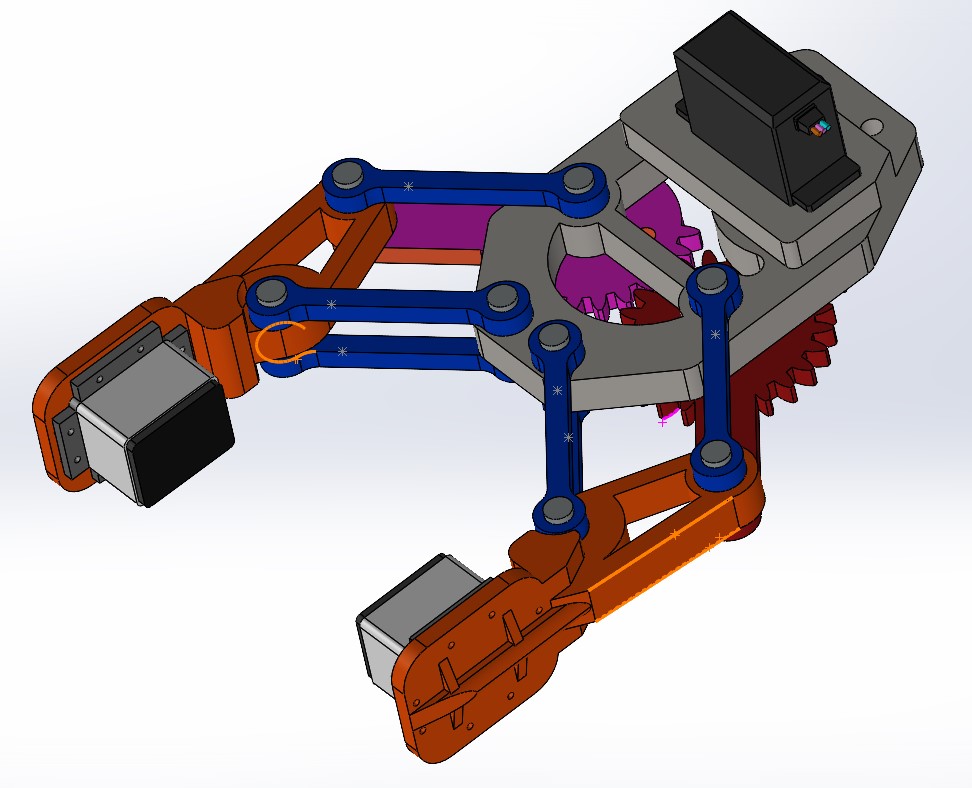
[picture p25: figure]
机械夹爪与传感器配合的全结构照片

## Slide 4

1.1 Gripper Design & Tactile Feedback Loop

The Principles of Visuo-Tactile Closed-Loop Control：

- Phase 1: Pre-Calibration & Initial Approach
I. Calibration Force Setting: Upon system initialization, a safe and basic "calibration grasping force" is preset as the initial target.
II. Initial Closure: The controller sends an open-loop command to the MG996R servo, driving the gripper to close until the silicone surface just contacts the object and reaches an initial, slight force state.
- Phase 2: Photometric Perception & 3D Reconstruction
I. Capturing Illumination Distortion: As the silicone deforms under pressure, the light intensity and shadows generated by the internal LED array change subtly. The OV5640 camera captures these high-resolution image signals in real-time.
II. Image to Tactile Force: The Raspberry Pi uses photometric stereo algorithms to perform a 3D geometric reconstruction of the contact surface based on light intensity changes, thereby accurately calculating the current physical contact force and stress distribution.

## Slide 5

1.1 Gripper Design & Tactile Feedback Loop

- Phase 3: Error Calculation & Dynamic Fine-Tuning
I. Real-Time Correction: The Raspberry Pi calculates the error between the "3D-reconstructed real-time force" and the "calibration force" at a high frequency.
II. Flexible Adaptation: If the current force is less than the calibration force, it fine-tunes the PWM signal to slowly increase pressure; if the force is too high, it slightly opens the gripper. Through this millimeter-level dynamic adjustment, it achieves a perfect "soft grasp" on fragile or unknown-hardness objects.
- Phase 4: Slip Warning & Transient Response
I. Shear Force Monitoring: During the 3D reconstruction, if dynamic downward displacement of the contact surface texture is detected (i.e., a sudden change in shear force), the system immediately determines that the object is slipping.
II. Anti-Slip Interrupt: It triggers the highest-priority control, instantaneously increasing the servo's closing angle to lock the object, and automatically switches back to the regular force fine-tuning loop once stabilized.

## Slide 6

1.1 Gripper Design & Tactile Feedback Loop

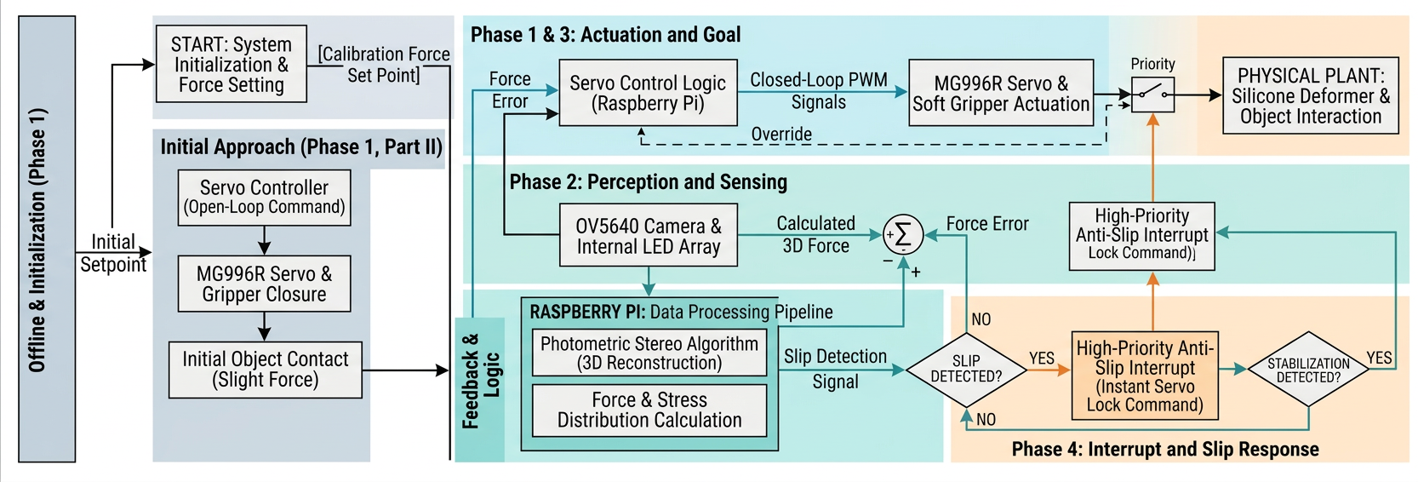
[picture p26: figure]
gemini-3.1-flash-image-preview (nano-banana-2)_a_根据这两张图片中描述的闭环控制逻辑来帮我

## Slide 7

1.2 Refining the BOM details

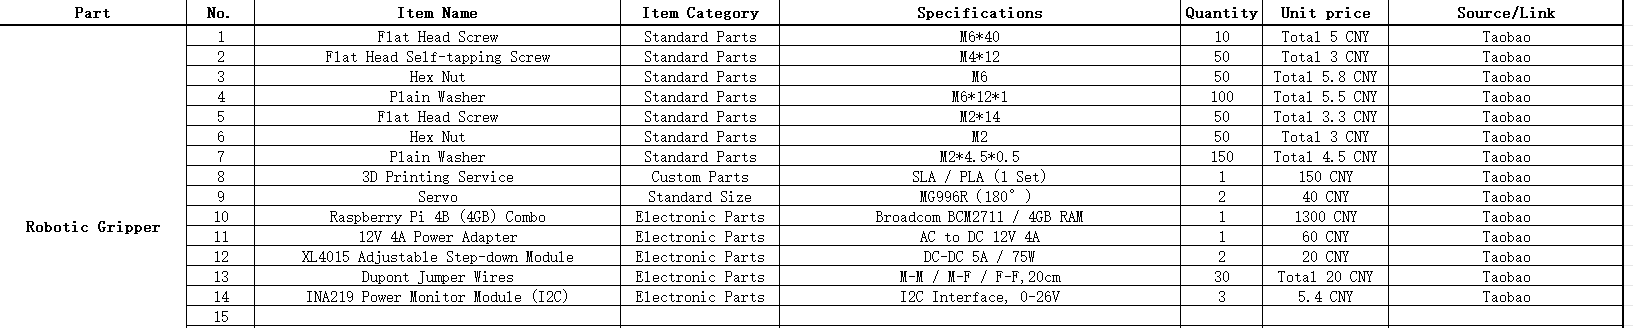
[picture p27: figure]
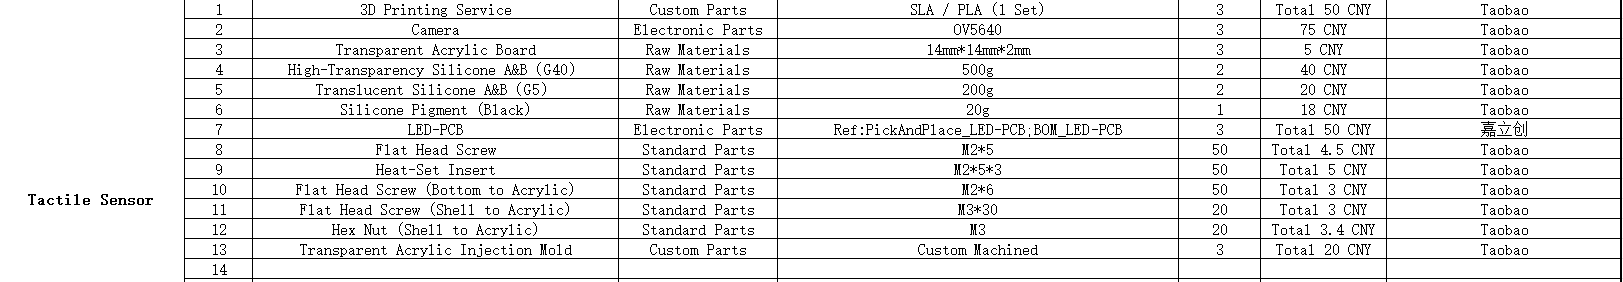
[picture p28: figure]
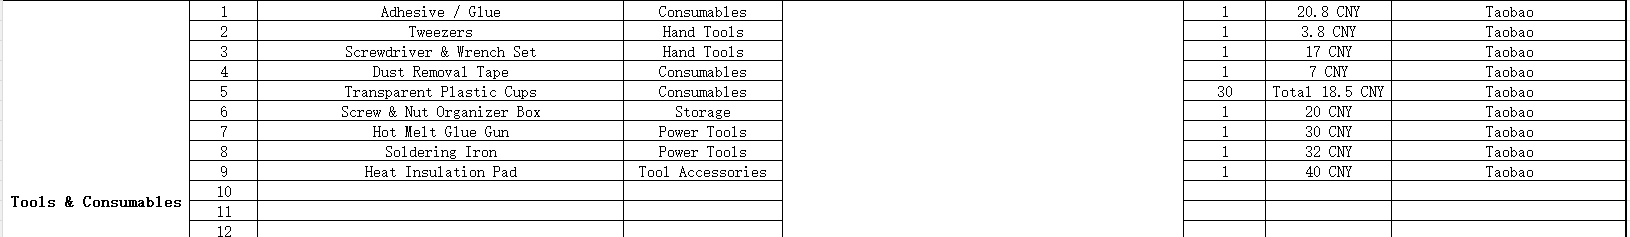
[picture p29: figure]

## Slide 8

02.

Project Plan for the Next Two Months

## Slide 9

Plan (Late April - Early July)

- Phase 1: Hardware Assembly & Preparation (Late April - Mid May)
- Key Tasks:
- Complete the silicone molding of the visuo-tactile sensor
- Complete the isolated wiring (high/low voltage) of the gripper.
- Critical Challenge:
- Optical-grade Silicone Molding. A vacuum degasser must be used to ensure the silicone is free of bubbles; otherwise, it will severely disrupt subsequent visual feature extraction.

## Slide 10

Plan (Late April - Early July)

- Phase 2: Visuo-Tactile Model Training & Calibration (Mid May - Mid June). . . . .[CORE FOCUS]
- Key Tasks:
- Data Collection: Use the lab's 6D force sensor as Ground Truth. Implement strict timestamp synchronization via Python to collect paired datasets of "OV5640 internal deformation images" and "actual 6D force/torque values" during compression.
- OpenCV Preprocessing: Use OpenCV to calculate the Difference Image between the loaded frame and the initial frame to filter out static backgrounds. Retain only deformation shadows caused by LED illumination distortion, crop the ROI, and convert to Tensors.
- PyTorch Training: Construct a Regression Task neural network on the workstation. Use a lightweight Backbone (e.g., MobileNetV3 or ResNet-18) for feature extraction to output 6D force predictions. Update model weights using MSE Loss and the Adam optimizer.
- Critical Challenge:
- Spatiotemporal Alignment & Inference Acceleration. Millisecond-level alignment of images and force data is a prerequisite. Meanwhile, the PyTorch model must be exported to ONNX format to ensure real-time control (<50ms per forward pass) on the Raspberry Pi.

High-level AI

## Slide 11

Plan (Late April - Early July)

- Phase 3: Closed-Loop System Debugging & Optimization (Late June - Early July)
- Key Tasks:
- Deploy the lightweight model to the Raspberry Pi. Execute the complete closed-loop of "visual force measurement -> error calculation -> PWM servo adjustment", conducting flexible grasping and anti-slip response tests.
- Critical Challenge:
- Stability of Closed-Loop Response. It requires overcoming the physical latency of the motor and optimizing the trigger sensitivity of the "anti-slip interrupt" mechanism to prevent system oscillation.

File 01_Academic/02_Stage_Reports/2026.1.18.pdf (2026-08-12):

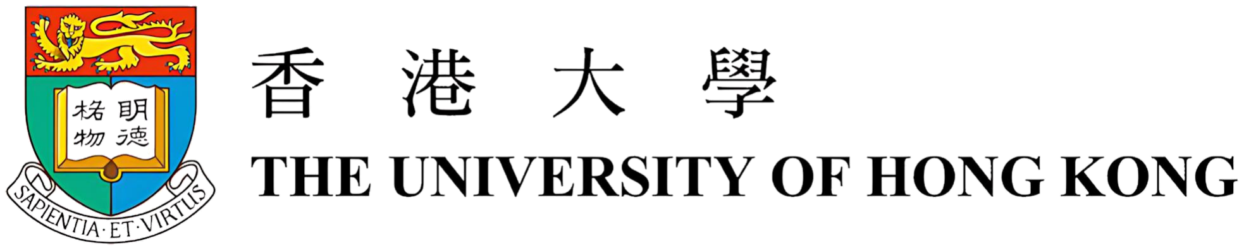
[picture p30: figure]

## 香港大学答辩模版

# AIF-HKU Capstone Project

## The Fabrication of Tactile Sensors and the Construction of Test Environment

## Name: Liu Zhaolin Date: 18/01/2026

# CONTENTS

# 1. Fabrication of Tactile Sensors （9DTact）

# 2. Construction of Test Environment ＆ Pressure-Sensitive Image Demo

# Fabrication of Tactile Sensor

01.

## 1.1 The Structure of Tactile Sensor


### 1. Fabrication of Tactile

Sensor

2.Construction of Test Environment ＆ Pressure-Sensitive Image Demo

## 1.2 Physical Photo of the Sensor


### 1. Fabrication of Tactile

Sensor

### 2. Construction of Test Environment ＆ Pressure-Sensitive

Image Demo

non-operating state | operating state

## 1.3 Fabrication Difficulties


1. Tactile System | 2. BiDexHand

## （1）Coating Uniformity: The reflective layer on the silicone must be applied with extreme precision to prevent optical signal distortion. （2）Bubble Control: Vacuum degassing is

## mandatory during silicone casting to eliminate air pockets that cause image artifacts. （3）Light Source: LEDs require precise

## equidistant soldering to ensure a perfectly

uniform internal light field for 3D reconstruction.

### 1. Fabrication of Tactile

Sensor

2.Construction of Test Environment ＆ Pressure-Sensitive Image Demo

# Construction of Test Environment ＆ Pressure-Sensitive Image Demo

02.

## 2.1 The Process of Construction ＆ Test

Setup ＆ Installation; Camera Calibration; Sensor Calibration; Shape Reconstruction; Force Estimation; Training; calibration first.; Create a Pressure- Sensitive Image

1. Research background &
1. Fabrication of Tactile
significance
Sensor

2.Integration with
2.Construction of Test Environment ＆ Pressure-Sensitive
former model
Image Demo

Display copy: third-party
robot photo omitted.

Our sensor adopts the
OV5647 camera module, which requires

The entire environment is set
up on the Ubuntu 20.04
system，Python Version：3.8
PyTorch Version：1.10
ROS Verson：ROS1

## 2.2 Some Relevant Code


### 1. Research background &

significance

2.Integration with
former model 1. Fabrication of Tactile Sensor

2.Construction of Test Environment ＆ Pressure-Sensitive Image Demo

## 2.3 Video of Testing Process

Setup ＆ Installation; Camera Calibration; Sensor Calibration; Training

## 香港大学答辩模版

# Thanks！

## Name: Liu Zhaolin Date: 18/01/2026

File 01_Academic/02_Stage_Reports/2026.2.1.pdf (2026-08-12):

# AIF-HKU Capstone Project

### Name: Liu Zhaolin Date: 01/02/2026

# CONTENTS

## 1. Generation and Visualization of Mixed Images

## 2. Measurement and Visualization of 6-Axis Force

## 3. Current Technical Difficulties

# Generation and Visualization of Mixed Images

01.

## 1.1 Fusion Mechanism and Physical Significance of Mixed Images


## 1.2 Demonstration of Mixed Image Generation Procedures


## 1.2 Demonstration of Mixed Image Generation Procedures


## 1.3 Code Implementation for Mixed Image Visualization


# Measurement and Visualization of 6-Axis Force

02.

## 2.1 Demonstration of 6D Force Measurement and Visualization


## 2.2 Code Implementation for 6D Force Visualization


## High-level AI

# Current Technical Difficulties

03.

## 3.1 The Main Difficulty —— New Model Training

# Why?

Since there are unavoidable physical differences
between my sensor and the original one, the pretrained model doesn't fit my hardware well. On top of that, I plan to optimize the structure—like

making the gel thinner and changing the camera model. This will lead to even larger gaps between the data. So, I can't use the open-source model anymore. I

have to train a new model from scratch to make sure

the force measurement is accurate. | How to do next？
| Requirement: High-precision Torque Sensor. Role: Provides Ground Truth data to pair with tactile
| images. Method: Collaborative/Synchronized Training. Goal: Use Deep Learning to map visual deformation

features to physical force vectors.

## 3.2 Selection and Market Research of Force/Torque Sensors

Display copy: manufacturer product images omitted.

This page originally documented reference force/torque sensor selection.
Refer to manufacturer sources for product specifications and images. No test data or measured performance is reported on this page.


# Thanks！

### Name: Liu Zhaolin Date: 01/02/2026

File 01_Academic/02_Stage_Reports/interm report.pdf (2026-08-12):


# Progress Report

2026 W15 - W16

## Name: Liu Zhaolin Date: 19/04/2026

# CONTENTS

# 1. Progress Report for the Past Two Weeks

# 2. Project Plan for the Next Two Months

# 1.1 Gripper Design & Tactile Feedback Loop


## Aimming to provide a reliable physical validation platform for the application and performance testing of tactile

sensors，I designed a robotic gripper.

# 1.1 Gripper Design & Tactile Feedback Loop

## The Principles of Visuo-Tactile Closed-Loop Control：

I. Calibration Force Setting: Upon system initialization, a safe and basic "calibration grasping force" is preset as the initial target. II. Initial Closure: The controller sends an open-loop command to the MG996R servo, driving the gripper to close until the

silicone surface just contacts the object and reaches an initial, slight force state.

I. Capturing Illumination Distortion: As the silicone deforms under pressure, the light intensity and shadows generated by the internal LED array change subtly. The OV5640 camera captures these high-resolution image signals in real-time. II. Image to Tactile Force: The Raspberry Pi uses photometric stereo algorithms to perform a 3D geometric reconstruction of

the contact surface based on light intensity changes, thereby accurately calculating the current physical contact force and stress distribution.

# 1.1 Gripper Design & Tactile Feedback Loop

I. Real-Time Correction: The Raspberry Pi calculates the error between the "3D-reconstructed real-time force" and the "calibration force" at a high frequency. II. Flexible Adaptation: If the current force is less than the calibration force, it fine-tunes the PWM signal to slowly increase

pressure; if the force is too high, it slightly opens the gripper. Through this millimeter-level dynamic adjustment, it achieves a perfect "soft grasp" on fragile or unknown-hardness objects.

I. Shear Force Monitoring: During the 3D reconstruction, if dynamic downward displacement of the contact surface texture is detected (i.e., a sudden change in shear force), the system immediately determines that the object is slipping. II. Anti-Slip Interrupt: It triggers the highest-priority control, instantaneously increasing the servo's closing angle to lock the

object, and automatically switches back to the regular force fine-tuning loop once stabilized.

# 1.1 Gripper Design & Tactile Feedback Loop


# 1.2 Refining the BOM details


# Project Plan for the Next Two Months

02.

# Plan (Late April - Early July)


u Key Tasks:
Ø Complete the silicone molding of the visuo-tactile sensor
Ø Complete the isolated wiring (high/low voltage) of the gripper. u Critical Challenge:

Ø Optical-grade Silicone Molding. A vacuum degasser must be used to ensure the silicone is free of bubbles; otherwise, it will severely disrupt subsequent visual feature extraction.

# Plan (Late April - Early July)


# High-level AI

## . . . . .[CORE FOCUS]

u Key Tasks:
Ø Data Collection:

Ø OpenCV Preprocessing:

Ø PyTorch Training: Construct a Regression Task neural network on the workstation. Use a lightweight Backbone (e.g., MobileNetV3 or ResNet-18) for feature extraction to output 6D force predictions. Update model weights using MSE Loss and

the Adam optimizer. u Critical Challenge:

Ø Spatiotemporal Alignment & Inference Acceleration. Millisecond-level alignment of images and force data is a prerequisite. Meanwhile, the PyTorch model must be exported to ONNX format to ensure real-time control (<50ms per forward pass) on the

Raspberry Pi.

# Plan (Late April - Early July)


u Key Tasks:
Ø Deploy the lightweight model to the Raspberry Pi. Execute the complete closed-loop of "visual force measurement -> error calculation -> PWM servo adjustment", conducting flexible grasping and anti-slip response tests. u Critical Challenge:

Ø Stability of Closed-Loop Response. It requires overcoming the physical latency of the motor and optimizing the trigger sensitivity of the "anti-slip interrupt" mechanism to prevent system oscillation.

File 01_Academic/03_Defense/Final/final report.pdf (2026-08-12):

# Development of a Compact Vision-Based Tactile Sensor for Robotic End Effectors

LIU Zhaolin

Supervisor: Wei Liu
Co-supervisor: Dr. WEI Yan

7 August 2026


Completed compact sensor prototypes

## 9DTact Sensing Principle


MSc Mechanical Engineering · The University of Hong Kong | 02

Internal camera observes contact-induced optical change

Internal image keeps contact shape visible

- Reference image records the surface before contact
- Contact image captures the optical change
- Difference image maps to depth and 3D shape
- RGB changes support six-axis force learning

## Project Aim and Technical Scope

01
Design


→

02
Fabrication

→

03
Distortion

→

04
Depth

→

05
Shape

→

06
FT300

Completed in this project

- Compact sensor design and physical fabrication
- My manual-point distortion script
- My depth script and fine 3D test
- FT300 platform and initial data test

Planned next stage

- Large image–FT300 dataset
- Six-axis model training
- Model evaluation after training

Initial data test completed; no force accuracy claimed.

## Overall Sensor Architecture


Exploded view of the complete optical–mechanical stack

Component groups

- G25/G5/G50 contact
layers
- Acrylic window
supports optics
- Eight-LED PCB
surrounds camera
- Camera, ring and
sensor base
- Enclosure, mounts and
cable outlet

Contact → optical change
Camera image → depth map

## Camera, Illumination and Electronics


Compact camera and separate decoder | Eight-LED PCB around the lens | Camera locating and retaining parts

Why the structure and calibration changed together

- Camera head stays inside the sensor | • Decoder board remains outside the
housing
- Eight LEDs surround the central lens | • Lens and LED alignment affect every
image
- New optics require sensor-specific
calibration

## Mechanical Housing and Cable Protection


Locating, retaining and mounting structure | Printed housings prepared for assembly
- Housing fixes camera working distance | • Window supports the tactile interface
- Cable clearance prevents screw pinching | • Cable stays outside the main load path

## Three-Layer Silicone Interface


Each layer has a different optical and mechanical role

G50 · transparent
support
Main optical path and
support

G5 · soft layer

Concentrates local
deformation

G25 · black contact
surface
Blocks ambient light at
contact
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

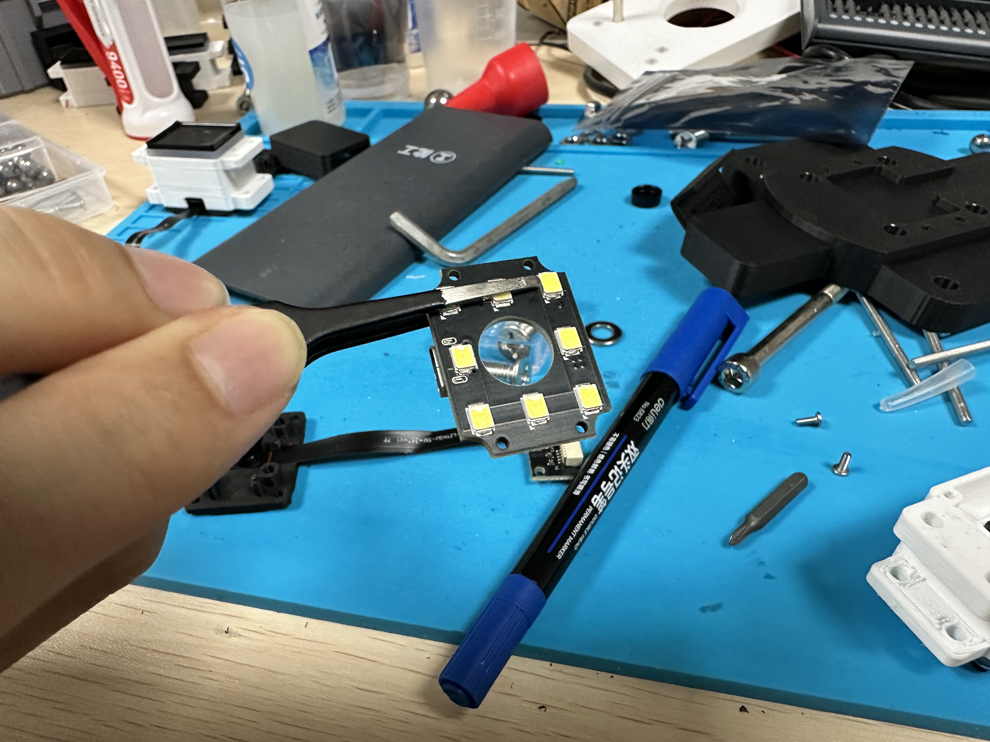
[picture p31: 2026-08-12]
03_Hardware/07_PCB_and_Electronics/Photos/led_pcb_and_camera.jpg

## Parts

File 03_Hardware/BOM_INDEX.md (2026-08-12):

# BOM Index

The original BOM workbook content is preserved without rewriting supplied fields.

| Scope | Authoritative file | Material/component rows | SHA-256 |
|---|---|---:|---|
| Project master and procurement | `05_BOM/Mechanical/Project_Master_BOM.xlsx` | 38 | `dabc9d9a6a223cc3f4473868fe6af32bd5dd70fe05e12d8f4c5ffc5b1d54783e` |
| LED PCB electronics | `05_BOM/Electronics/BOM_LED-PCB.xlsx` | 4 | `17d79c93ef6d8cb6d7491cbfa933d972dbbd88575ff4919e45f962d60aa950c0` |

The project master BOM covers vision components, mechanical parts, fabrication, tools, materials, and LED-PCB child lines. The electronics BOM is used together with the retained pick-and-place workbook and Gerber set.

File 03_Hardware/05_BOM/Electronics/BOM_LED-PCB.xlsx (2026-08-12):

No. | Quantity | Comment | Designator | Footprint | Value | Manufacturer Part | Manufacturer | Supplier Part | Supplier
1 | 8 | BZ-S2835BW9C1-02-3V-UV | LED1,LED2,LED3,LED4,LED5,LED6,LED7,LED8 | LED-SMD_L3.5-W2.8-FD-2835_WHITE |  | BZ-S2835BW9C1-02-3V-UV | baizou(百洲） | C2833052 | LCSC
2 | 1 | 20kΩ | R1 | R0805 | 20kΩ | RT0805CRE0720KL | YAGEO(国巨) | C706298 | LCSC
3 | 1 | CN5711 | U1 | SOIC-8_L5.0-W4.0-P1.27-LS6.0-BL-EP2.0 |  | CN5711 | CONSONANCE(上海如韵) | C35634 | LCSC
4 | 1 | MICRO-02-G4P1-A1T2 | USB3 | MICRO-USB-SMD_MICRO-02-GXPX-A1T2 |  | MICRO-02-G4P1-A1T2 | Yuandi(台湾元迪) | C2682525 | LCSC

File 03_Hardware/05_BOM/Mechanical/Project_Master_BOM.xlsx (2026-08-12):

Category | Item Name | Specification / Model | Quantity | Unit | Unit Price (RMB) | Total (RMB) | Source
Camera / Vision | OV5640 camera module with USB cable | 5 MP OV5640 USB camera module; auto-focus; 160-degree wide-angle lens | 1 | set | 70.60 | 70.60 | V01
Fasteners | 304 stainless flat washer | M6 x 12 x 1.5; enlarged/thickened flat washer; 50 pcs/pack | 1 | pack | 2.85 | 2.85 | V02
Fasteners | 304 stainless hex nut | M6 hex nut; 50 pcs/pack | 1 | pack | 2.51 | 2.51 | V02
Tools | Hex key wrench set | Greenwood/Lvlin inner hex wrench set; 9-piece ball-end long-arm set | 1 | set | 15.89 | 15.89 | V03
Fasteners | 304 stainless countersunk screw | Cross recessed flat/countersunk head machine screw; M6 x 18; 20 pcs/pack | 1 | pack | 3.84 | 3.84 | V04
Fasteners | 304 stainless countersunk screw | Cross recessed flat/countersunk head machine screw; M3 x 45; 50 pcs/pack | 1 | pack | 5.68 | 5.68 | V04
Tools | Mini bench vise | Small desktop bench vise / clamp for prototype fabrication | 1 | set | 21.80 | 21.80 | V05
Sheet material | Transparent acrylic / PC plate | Transparent acrylic / PC / PVC sheet; custom-cut plate for prototype panel | 8 | pcs | 4.75 | 38.00 | V06
Sheet material | PMMA acrylic sheet | High-transparency PMMA acrylic sheet; CNC cutting / UV printing / custom processing; 1 x 1 mm option shown | 3 | pcs | 10.00 | 30.00 | V07
Fabrication service | 3D printing service | High-precision resin/nylon 3D printing service for prototype parts | 26 | pcs | 10.00 | 260.00 | V08
Molding material | AB resin / silicone material | Manual-purpose silicone / AB resin; clear type; 25-degree; 200 g | 1 | bottle/set | 24.00 | 24.00 | V09
Molding material | AB resin / silicone material | Manual-purpose silicone / AB resin; clear type; 25-degree; 300 g | 1 | bottle/set | 30.00 | 30.00 | V09
Molding material | AB silicone pigment | Food-grade AB silicone color paste; black; 20 g | 1 | bottle | 17.37 | 17.37 | V10
Molding material | PDMS transparent mold silicone | High-transparency silicone for molds; 6-8 h curing; 500 g; G50 bubble-removal option; net retained after refunds | 1 | set | 37.54 | 37.54 | V10
Cable | Micro USB data / charging cable | Ugreen Micro USB cable; 0.5 m; USB 2.0; black | 1 | pcs | 11.90 | 11.90 | V11
Tools | Mini bench vise | Small bench vise / table clamp for prototype work | 1 | set | 37.00 | 37.00 | V12
Camera / Vision | OV5640 camera module | 5 MP OV5640 USB camera module; auto-focus; 160-degree wide-angle lens | 1 | pcs | 71.00 | 71.00 | V13
Adhesive | B7000 / T7000 adhesive | Waterproof adhesive; black; 9400-series/general repair adhesive shown in order title | 1 | tube | 17.82 | 17.82 | V14
Fasteners | 304 stainless hex nut | M3 hex nut; 200 pcs/pack | 1 | pack | 4.37 | 4.37 | V15
Fasteners | 304 stainless flat-head screw | Cross recessed flat-head screw; M3 x 30; 20 pcs/pack | 1 | pack | 3.23 | 3.23 | V15
Fasteners | 304 stainless flat-head screw | Cross recessed flat-head screw; M2 x 6; 100 pcs/pack | 1 | pack | 4.45 | 4.45 | V15
Fasteners | 304 stainless flat-head screw | Cross recessed flat-head screw; M2 x 5; 100 pcs/pack | 1 | pack | 4.02 | 4.02 | V15
Fasteners | M2/M3 brass insert nut | Heat-set knurled brass insert nut; M2 x 5 x 3; 100 pcs/pack; for M4/M5/M6/M8 related sizes listing | 1 | pack | 7.73 | 7.73 | V15
Tools | Soldering / repair heat-insulation mat | A802 medium silicone repair/soldering mat; approx. 22 x 29 cm; blue | 1 | pcs | 39.80 | 39.80 | V16
Tools | Electric soldering iron kit | Deli 60 W temperature-adjustable electric soldering iron kit; plus welding/maintenance accessory set | 1 | set | 32.40 | 32.40 | V16
Tools | Anti-static tweezers | Stainless anti-static tweezers; insulated coating; pointed/flat repair tool | 1 | pcs | 3.42 | 3.42 | V17
Consumables | Dust removal film / sticker | Blue low-tack dust-removal adhesive film; 20 sheets | 1 | pack | 6.80 | 6.80 | V18
Tools | Heat-resistant measuring cup / container | Transparent heat-resistant measuring cup/container; approx. 200 ml; high-temperature material | 1 | pcs | 18.80 | 18.80 | V19
Tools | Hot glue gun | Deli hot-melt glue gun; 40 W industrial/home use; 7-11 mm glue stick compatible; 10 glue sticks included | 1 | set | 29.90 | 29.90 | V20
Storage | Small component storage box | 30-compartment SMD/component storage box; independent lids; for screws/electronic components | 1 | pcs | 22.80 | 22.80 | V21
Electronic component | LED component pack | BZ-S2835BW9C1-02-3V-UV white 2835 SMD LED; 20 pcs/pack | 3 | packs | 3.84 | 11.52 | V22
PCB fabrication | JLCPCB LED PCB fabrication and SMT assembly | FR-4; 2 layers; 1.6 mm; 7.1 cm x 7.0 cm; black solder mask; white silkscreen; 5 boards; SMT assembly included | 5 | boards | 102.56 | 512.79 | V23
Camera / Vision | OV5640 camera module | 5 MP OV5640 camera module; integrated auto-focus; wide-angle USB driverless module; 160-degree wide-angle lens | 2 | pcs | 73.60 | 147.20 | V24
Mechanical component | 304 stainless steel precision bearing ball | 304 stainless bearing ball / solid steel ball; 8 mm; 50 pcs/pack | 1 | pack | 9.42 | 9.42 | V25
LED PCB schematic BOM | LED PCB component - BZ-S2835BW9C1-02-3V-UV | Designator: LED1,LED2,LED3,LED4,LED5,LED6,LED7,LED8; Footprint: LED-SMD_L3.5-W2.8-FD-2835_WHITE; MPN: BZ-S2835BW9C1-02-3V-UV; Manufacturer: baizou(百洲）; LCSC/Supplier part: C2833052 | 8 | pcs |  |  | BOM_LED-PCB.xlsx
LED PCB schematic BOM | LED PCB component - 20kΩ | Designator: R1; Value: 20kΩ; Footprint: R0805; MPN: RT0805CRE0720KL; Manufacturer: YAGEO(国巨); LCSC/Supplier part: C706298 | 1 | pcs |  |  | BOM_LED-PCB.xlsx
LED PCB schematic BOM | LED PCB component - CN5711 | Designator: U1; Footprint: SOIC-8_L5.0-W4.0-P1.27-LS6.0-BL-EP2.0; MPN: CN5711; Manufacturer: CONSONANCE(上海如韵); LCSC/Supplier part: C35634 | 1 | pcs |  |  | BOM_LED-PCB.xlsx
LED PCB schematic BOM | LED PCB component - MICRO-02-G4P1-A1T2 | Designator: USB3; Footprint: MICRO-USB-SMD_MICRO-02-GXPX-A1T2; MPN: MICRO-02-G4P1-A1T2; Manufacturer: Yuandi(台湾元迪); LCSC/Supplier part: C2682525 | 1 | pcs |  |  | BOM_LED-PCB.xlsx
 |  |  |  |  | Priced subtotal | 1556.45

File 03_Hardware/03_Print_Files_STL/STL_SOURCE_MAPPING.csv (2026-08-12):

stl_file | stl_size | stl_sha256 | triangle_count | unitless_bounds | solidworks_source | solidworks_size | solidworks_sha256 | validation | unit_status | correspondence_basis
03_Hardware/03_Print_Files_STL/Converted/SolidWorks_Parts/Calibration/calibration_board.STL | 2718984 | 6426f6af7bb57ed5bd4945c59cd14600b31608109dfe3266e53ca9088b79903c | 54378 | 37 x 11 x 30 | 03_Hardware/01_CAD_Source/SolidWorks_Parts/Calibration/calibration_board.SLDPRT | 363089 | 20e574592fc46801cc4254c495c2424cd15390290423e8ea4e59f9d99efb9ada | PASS: binary size/count, finite values, no degenerate or duplicate triangles, one component, closed 2-manifold after 1e-7 coordinate weld | [TO CONFIRM] | Exact normalized filename stem + embedded STL header; geometric revision identity not independently proven
03_Hardware/03_Print_Files_STL/Converted/SolidWorks_Parts/Optimized_Sensor/acrylic_window.STL | 684 | 12332dae3063af5b44bbc68a2160d22be12bd4f6c8438ab27b3c59a92f2eba93 | 12 | 14 x 2 x 14 | 03_Hardware/01_CAD_Source/SolidWorks_Parts/Optimized_Sensor/acrylic_window.SLDPRT | 113710 | db339570dd11e936abc3d00144f940362a76a9457c7bd763cb6525b1a5ffe8ac | PASS: binary size/count, finite values, no degenerate or duplicate triangles, one component, closed 2-manifold after 1e-7 coordinate weld | [TO CONFIRM] | Exact normalized filename stem + embedded STL header; geometric revision identity not independently proven
03_Hardware/03_Print_Files_STL/Converted/SolidWorks_Parts/Optimized_Sensor/isolation_ring.STL | 28884 | 4d3ea57472716b995fb6fda1efd796c4323e3c56fa7c4fd044aa74c4e86f4cc1 | 576 | 11.9000006 x 2.79999995 x 11.9000006 | 03_Hardware/01_CAD_Source/SolidWorks_Parts/Optimized_Sensor/isolation_ring.SLDPRT | 428666 | ea57e9d43094f71fde8e520f46240cf10dd2b9270f3f743cf5d25ca738db4c79 | PASS: binary size/count, finite values, no degenerate or duplicate triangles, one component, closed 2-manifold after 1e-7 coordinate weld | [TO CONFIRM] | Exact normalized filename stem + embedded STL header; geometric revision identity not independently proven
03_Hardware/03_Print_Files_STL/Converted/SolidWorks_Parts/Optimized_Sensor/sensor_base.STL | 391284 | 6bdc65bc01b6bd15e9eeab87fe375c6d98af427cfd46e86e2b7e1b7a60a26095 | 7824 | 32.5 x 8.5 x 25.5 | 03_Hardware/01_CAD_Source/SolidWorks_Parts/Optimized_Sensor/sensor_base.SLDPRT | 315147 | 52aa7b718a13a1e016435853df094ccc270ecf1d830b233554c87ec9df79c21c | PASS: binary size/count, finite values, no degenerate or duplicate triangles, one component, closed 2-manifold after 1e-7 coordinate weld | [TO CONFIRM] | Exact normalized filename stem + embedded STL header; geometric revision identity not independently proven
03_Hardware/03_Print_Files_STL/Converted/SolidWorks_Parts/Optimized_Sensor/sensor_shell_optimized.STL | 150984 | 9ac971578ed41aa10b907d9fcbaee525c7c08b5f6a96b728dddacf5cce539123 | 3018 | 48.5 x 20.7000008 x 25.5 | 03_Hardware/01_CAD_Source/SolidWorks_Parts/Optimized_Sensor/sensor_shell_optimized.SLDPRT | 385022 | 89f06e29cbd3a185486ce5b376776283824c6cda9ed0376a3581c65836ee1ff5 | PASS: binary size/count, finite values, no degenerate or duplicate triangles, one component, closed 2-manifold after 1e-7 coordinate weld | [TO CONFIRM] | Exact normalized filename stem + embedded STL header; geometric revision identity not independently proven
03_Hardware/03_Print_Files_STL/Converted/SolidWorks_Parts/Test_Connections/FT300_connection base.STL | 127384 | a26f688f5753b5e801c8cbe0222a24111181c945795fa5f2585a85c913c2ad9e | 2546 | 130 x 80 x 12 | 03_Hardware/01_CAD_Source/SolidWorks_Parts/Test_Connections/FT300_connection base.SLDPRT | 124944 | 4656feaddc7c1031ad097d4601da9650c6be078923154c49ff11c89f2754e3be | PASS: binary size/count, finite values, no degenerate or duplicate triangles, one component, closed 2-manifold after 1e-7 coordinate weld | [TO CONFIRM] | Exact normalized filename stem + embedded STL header; geometric revision identity not independently proven
03_Hardware/03_Print_Files_STL/Converted/SolidWorks_Parts/Test_Connections/sensor_connection base.STL | 198484 | 95dfea1caacb2bd53f2c83b29a56d7e10620fe59822faa75ab0ffdf662d079a3 | 3968 | 100 x 140 x 14 | 03_Hardware/01_CAD_Source/SolidWorks_Parts/Test_Connections/sensor_connection base.SLDPRT | 276096 | 7ae5e1779101a9c6e4c53ccf6a349f9b4c223d3725794ed86c03babcb5b09660 | PASS: binary size/count, finite values, no degenerate or duplicate triangles, one component, closed 2-manifold after 1e-7 coordinate weld | [TO CONFIRM] | Exact normalized filename stem + embedded STL header; geometric revision identity not independently proven

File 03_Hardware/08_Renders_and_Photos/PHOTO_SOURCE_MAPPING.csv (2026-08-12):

original_filename | final_relative_path | size | sha256 | width_px | height_px | classification | display_priority | description | provenance
9Dtact原理图.png | 03_Hardware/08_Renders_and_Photos/Technical_Diagrams/9dtact_system_architecture.png | 272396 | f3161ae9320435fa579cd978bc1660d2fe9ed3bc778d644b8ecee17c03954095 | 1383 | 588 | Technical_Diagram | Supporting | 9DTact processing and force-estimation architecture diagram. | Author project image source folder; source file retained unchanged
LEDpcb板.jpg | 03_Hardware/07_PCB_and_Electronics/Photos/led_pcb_and_camera.jpg | 1876689 | 4185d9fc3a4efe7c8ed4729a520de2f50fa6f8fe71161c425d6ba4d7af62d821 | 4032 | 3024 | Electronics_Photo | Key | LED PCB and camera illumination hardware close-up. | Author project image source folder; source file retained unchanged
三层硅胶的意义.png | 03_Hardware/08_Renders_and_Photos/Technical_Diagrams/three_layer_silicone_concept.png | 307098 | de7384003eab089e6f06e533684f9cfe5ff318552175d977d947707865359f13 | 1170 | 607 | Technical_Diagram | Key | Three-layer silicone optical and deformation concept diagram. | Author project image source folder; source file retained unchanged
传感器基本结构原理图.png | 03_Hardware/08_Renders_and_Photos/Technical_Diagrams/sensor_optical_structure.png | 1814916 | 2fb8f37576233d76691a3ef0544677e4c97d707047666603721e0ab17027142d | 1448 | 1086 | Technical_Diagram | Key | Custom tactile sensor optical structure and image formation diagram. | Author project image source folder; source file retained unchanged
传感器电子元件集合.jpg | 03_Hardware/07_PCB_and_Electronics/Photos/sensor_electronics_components.jpg | 2063344 | 8fe513b7ab02fa9a2e60d9a8b885eab474e902e3d4c2db0d29a29a176b6334b6 | 4032 | 3024 | Electronics_Photo | Key | OV5640-style camera module, LED PCB and USB interface board. | Author project image source folder; source file retained unchanged
全新传感器和FT300六维力传感器装配进行传感器力标定的结构.jpg | 03_Hardware/08_Renders_and_Photos/Test_Setups/sensor_ft300_calibration_fixture.jpg | 1954955 | 8012360661a60c4bd08a90a70e13fc570db9b8c1e0b18f0ab0b4e78c217a6ae2 | 4032 | 3024 | FT300_Test_Setup | Key | Custom tactile sensor mounted on the FT300 mechanical test structure. | Author project image source folder; source file retained unchanged
多层注胶模具用胶枪封缝防漏液.jpg | 03_Hardware/09_Manufacturing_Notes/Process_Photos/mold_hot_glue_sealing.jpg | 1897101 | ac96b3e2538363a030a4811795b967033dfe42c25ecd296c2648d7fcaf44bc5b | 4032 | 3024 | Manufacturing_Process | Supporting | Injection-mold perimeter sealing with hot glue before silicone casting. | Author project image source folder; source file retained unchanged
多层注胶模具的创新.jpg | 03_Hardware/09_Manufacturing_Notes/Process_Photos/multi_layer_casting_molds.jpg | 2443928 | 312e085961e9c596c978e5ad3d5b333ab7a2b4552f2fa9ba6279f5830b65b14d | 4032 | 3024 | Manufacturing_Process | Key | Two assembled multi-layer silicone casting molds. | Author project image source folder; source file retained unchanged
工件打印.jpg | 03_Hardware/09_Manufacturing_Notes/Process_Photos/printed_mold_and_housing_parts.jpg | 2730447 | eddb064eaf2338c64e9604c441dc73500556dcfd391ec0225bc9a96317898e93 | 4032 | 3024 | Manufacturing_Process | Supporting | Collection of 3D-printed mold and housing components. | Author project image source folder; source file retained unchanged
最终全新传感器的装配完整产品图.jpg | 03_Hardware/08_Renders_and_Photos/Completed_Hardware/completed_dual_custom_sensors.jpg | 3007483 | 9ad80b064d03d74f02efb7f946442e12a19fa8622a0ac83fe0ac9737cfff8da8 | 4032 | 3024 | Completed_Hardware | Key | Two completed custom tactile sensors with camera cables. | Author project image source folder; source file retained unchanged
最终实现的精细shape reconstruction的动画界面（电脑端）.png | 04_Data_and_Models/03_Processed_Data/Shape_Reconstruction_Results/shape_reconstruction_result.png | 362712 | 6c66bba61930892c99345cd5a3913472c85c68d0f8314c6ecd13748b353e2aef | 2560 | 1600 | Shape_Reconstruction_Result | Key | Ubuntu GUI screenshot showing a 3D shape-reconstruction result. | Author project image source folder; source file retained unchanged
注胶（最底层全透明硅胶G50硬度）.jpg | 03_Hardware/09_Manufacturing_Notes/Process_Photos/transparent_g50_bottom_layer.jpg | 2054411 | 9b74e545dee58346e1e27013d876cdf11864969ab2c76d7eb6cf90361ef4bdb8 | 4032 | 3024 | Manufacturing_Process | Supporting | Transparent G50 bottom silicone layer after curing. | Author project image source folder; source file retained unchanged
测试台.jpg | 03_Hardware/08_Renders_and_Photos/Test_Setups/benchtop_sensor_test_fixture.jpg | 2514262 | b45d478903046f08ae8ed521c10d3ed7c32265a371034347c93ad9f216f02270 | 4032 | 3024 | Test_Setup | Key | Benchtop tactile-sensor test fixture with camera and cabling. | Author project image source folder; source file retained unchanged
深度标定所用小球（半径4mm）.jpg | 04_Data_and_Models/02_Calibration_Data/Documentation_Images/Depth_Calibration/depth_calibration_4mm_radius_indenter.jpg | 1742009 | 0876fac49751e40a97d02694395dd106ccbba521da1dff93db778ef30d1f494a | 4032 | 3024 | Depth_Calibration | Supporting | 4 mm radius spherical indenter used for depth calibration. | Author project image source folder; source file retained unchanged
深度标定的过程图.png | 04_Data_and_Models/02_Calibration_Data/Documentation_Images/Depth_Calibration/depth_calibration_process.png | 950904 | 5b64e6983b3686ae90c289e9e614f9f88d420fa140cace7102e032a9110c0604 | 2560 | 1600 | Depth_Calibration | Key | Ubuntu depth-calibration process screenshot with contact image. | Author project image source folder; source file retained unchanged
相机calibration所用的calibration board.jpg | 04_Data_and_Models/02_Calibration_Data/Documentation_Images/Camera_Calibration/camera_calibration_7x9_board.jpg | 1851031 | c7754d8856ec5bc6666be6845e8cfc7ce5b17517612c9655f44bafeaac0fb866 | 4032 | 3024 | Camera_Calibration | Key | Physical 7 by 9 calibration target used for camera mapping. | Author project image source folder; source file retained unchanged
相机的calibration过程以及手动calibration脚本的运用.png | 04_Data_and_Models/02_Calibration_Data/Documentation_Images/Camera_Calibration/manual_camera_calibration_63_point_gui.png | 825434 | 457f148deb5553c54699a7187a487858973587802a791c86a7592c774a41e860 | 2560 | 1600 | Camera_Calibration | Key | Manual camera calibration GUI with 63-point grid and preview. | Author project image source folder; source file retained unchanged
硅胶定型（中间层半透明硅胶G5硬度）.jpg | 03_Hardware/09_Manufacturing_Notes/Process_Photos/translucent_g5_middle_layer.jpg | 2441137 | 16d545e0bc1a21c7cf5a8bc497880d51db22647d7742f69b1e8002ec7a7aa176 | 4032 | 3024 | Manufacturing_Process | Supporting | Translucent G5 middle silicone layer after curing. | Author project image source folder; source file retained unchanged
硅胶定型（最上层黑色硅胶G25硬度）.jpg | 03_Hardware/09_Manufacturing_Notes/Process_Photos/black_g25_top_layer.jpg | 3058623 | f10274b986dd33c07fc80e3c99fb4903dc33b44d982c4becc7a3bff92b465f38 | 4032 | 3024 | Manufacturing_Process | Supporting | Black G25 top silicone layer after curing. | Author project image source folder; source file retained unchanged
硅胶的配置.jpg | 03_Hardware/09_Manufacturing_Notes/Process_Photos/silicone_material_preparation.jpg | 2819087 | e7f51551f84e35f34b44ea7865ace44749036307ec718c66637df60bf3d8b7b9 | 4032 | 3024 | Manufacturing_Process | Supporting | Silicone component preparation and manual mixing. | Author project image source folder; source file retained unchanged
硅胶真空消泡.jpg | 03_Hardware/09_Manufacturing_Notes/Process_Photos/silicone_vacuum_degassing.jpg | 2944349 | bffc14bcd7966eccc75197cfc7fe775c3678e67d5bfc71e2285e7bd76d279b33 | 4032 | 3024 | Manufacturing_Process | Key | Vacuum degassing apparatus and silicone cup. | Author project image source folder; source file retained unchanged
结构爆炸图2（标注版）.jpg | 03_Hardware/08_Renders_and_Photos/Assembly_and_Design/sensor_exploded_view_annotated.jpg | 112551 | 63ecef1cc2777c4a125a734b9db2fed50cc35b60acd2eb28778ab9ed4b7acc87 | 1747 | 994 | Assembly_Render | Key | Numbered exploded view of the tactile sensor assembly. | Author project image source folder; source file retained unchanged
自研夹爪的简易装配.png | 03_Hardware/08_Renders_and_Photos/Assembly_and_Design/custom_gripper_assembly_render.png | 275879 | 2424a1596b20bba572839eff15483661d8b2eeb20d8411ee61bdb231dd442341 | 1299 | 904 | Gripper_Render | Key | CAD rendering of the proposed custom gripper integration. | Author project image source folder; source file retained unchanged
螺丝压传感器.jpg | 03_Hardware/08_Renders_and_Photos/Test_Setups/screw_loading_sensor_test.jpg | 2407386 | af142b06239ddeda0a02e23a614da2dc260b46eb3c3b6e4aaa04cd174ab62230 | 4032 | 3024 | Assembly_Test | Supporting | Mechanical screw loading on the assembled tactile sensor. | Author project image source folder; source file retained unchanged

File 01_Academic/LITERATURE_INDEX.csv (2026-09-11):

reference_number | title | authors | year | purpose_and_thesis_sections | doi_or_url | citation_source | archived_literature_file | availability_status | verification_note | verified_title | verified_year | open_access_status | download_source | download_url | file_size_bytes | sha256 | pdf_readability
1 | Intelligence without Representation, | R. A. Brooks | 1991 | Chapter 1 Introduction / 1.1 Background and motivation | https://doi.org/10.1016/0004-3702(91)90053-M | 01_Thesis/Final/Dissertation_LIU Zhaolin.pdf | Not included in portfolio; use DOI or source URL | Link only; redistribution permission not established | Metadata checked against DOI/OpenAlex or the cited official source. Authoritative URL: https://doi.org/10.1016/0004-3702(91)90053-M. | Intelligence without representation | 1991 | Open access | MIT CSAIL course archive | https://courses.csail.mit.edu/6.803/pdf/brooks.pdf | 147457 | 9047e29098d99db1b09b145ea14bfd571a063fbc2d98068a182765ea8d56142e | Readable (12 pages)
2 | How the Body Shapes the Way We Think: A New View of Intelligence | R. Pfeifer and J. Bongard | 2006 | Chapter 1 Introduction / 1.1 Background and motivation |  | 01_Thesis/Final/Dissertation_LIU Zhaolin.pdf | Not archived; use authoritative URL | Unavailable after public-source checks | Metadata checked against DOI/OpenAlex or the cited official source. Authoritative URL: https://openalex.org/W1558521349. Publisher/book bibliographic record; no public full-text PDF identified. | How the Body Shapes the Way We Think: A New View of Intelligence | 2006 | Closed/metadata only |  |  |  |  | Not downloaded
3 | Trends and Challenges in Robot Manipulation, | A. Billard and D. Kragic | 2019 | Chapter 1 Introduction / 1.1 Background and motivation | https://doi.org/10.1126/science.aat8414 | 01_Thesis/Final/Dissertation_LIU Zhaolin.pdf | Not archived; use authoritative URL | Unavailable after public-source checks | Metadata checked against DOI/OpenAlex or the cited official source. Authoritative URL: https://doi.org/10.1126/science.aat8414. No public PDF URL found | Trends and challenges in robot manipulation | 2019 | Open access |  |  |  |  | Not downloaded
4 | Hands for Dexterous Manipulation and Robust Grasping: A Difficult Road toward Simplicity, | A. Bicchi | 2000 | Chapter 1 Introduction / 1.1 Background and motivation | https://doi.org/10.1109/70.897777 | 01_Thesis/Final/Dissertation_LIU Zhaolin.pdf | Not archived; use authoritative URL | Unavailable after public-source checks | Metadata checked against DOI/OpenAlex or the cited official source. Authoritative URL: https://doi.org/10.1109/70.897777. No public PDF URL found | Hands for dexterous manipulation and robust grasping: a difficult road toward simplicity | 2000 | Closed/metadata only |  |  |  |  | Not downloaded
5 | Tactile Sensing—From Humans to Humanoids, | R. S. Dahiya, G. Metta, M. Valle, and G. Sandini | 2010 | Chapter 2 Related Work / 2.1 Robotic tactile sensing technologies | https://doi.org/10.1109/TRO.2009.2033627 | 01_Thesis/Final/Dissertation_LIU Zhaolin.pdf | Not archived; use authoritative URL | Unavailable after public-source checks | Metadata checked against DOI/OpenAlex or the cited official source. Authoritative URL: https://doi.org/10.1109/TRO.2009.2033627. No public PDF URL found | Tactile Sensing—From Humans to Humanoids | 2009 | Open access |  |  |  |  | Not downloaded
6 | Robotic Tactile Perception of Object Properties: A Review, | S. Luo, J. Bimbo, R. Dahiya, and H. Liu | 2017 | Chapter 2 Related Work / 2.1 Robotic tactile sensing technologies | https://doi.org/10.1016/j.mechatronics.2017.11.002 | 01_Thesis/Final/Dissertation_LIU Zhaolin.pdf | Not included in portfolio; use DOI or source URL | Link only; redistribution permission not established | Metadata checked against DOI/OpenAlex or the cited official source. Authoritative URL: https://doi.org/10.1016/j.mechatronics.2017.11.002. | Robotic tactile perception of object properties: A review | 2017 | Open access | OpenAlex best OA location | https://kclpure.kcl.ac.uk/ws/files/82190471/robotic_tactile_perception_review_final.pdf | 2429940 | eaead2f573ae79e34dc83cebe8f0b471c84144077a3214b80add74a7b251dc6d | Readable (18 pages)
7 | Tactile Sensing in Dexterous Robot Hands—Review, | Z. Kappassov, J.-A. Corrales, and V. Perdereau | 2015 | Chapter 2 Related Work / 2.1 Robotic tactile sensing technologies | https://doi.org/10.1016/j.robot.2015.07.015 | 01_Thesis/Final/Dissertation_LIU Zhaolin.pdf | Not archived; use authoritative URL | Unavailable after public-source checks | Metadata checked against DOI/OpenAlex or the cited official source. Authoritative URL: https://doi.org/10.1016/j.robot.2015.07.015. No public PDF URL found | Tactile sensing in dexterous robot hands — Review | 2015 | Open access |  |  |  |  | Not downloaded
8 | Magnetic Nanocomposite Cilia Tactile Sensor, | A. Alfadhel and J. Kosel | 2015 | Chapter 2 Related Work / 2.1 Robotic tactile sensing technologies | https://doi.org/10.1002/adma.201504015 | 01_Thesis/Final/Dissertation_LIU Zhaolin.pdf | Not archived; use authoritative URL | Unavailable after public-source checks | Metadata checked against DOI/OpenAlex or the cited official source. Authoritative URL: https://doi.org/10.1002/adma.201504015. No public PDF URL found | Magnetic Nanocomposite Cilia Tactile Sensor | 2015 | Closed/metadata only |  |  |  |  | Not downloaded
9 | Retrographic Sensing for the Measurement of Surface Texture and Shape, | M. K. Johnson and E. H. Adelson | 2009 | Chapter 2 Related Work / 2.2 Representative vision-based tactile sensors | https://doi.org/10.1109/CVPR.2009.5206534 | 01_Thesis/Final/Dissertation_LIU Zhaolin.pdf | Not included in portfolio; use DOI or source URL | Link only; redistribution permission not established | Metadata checked against DOI/OpenAlex or the cited official source. Authoritative URL: https://doi.org/10.1109/CVPR.2009.5206534. | Retrographic sensing for the measurement of surface texture and shape | 2009 | Open access | MIT CSAIL author page | https://people.csail.mit.edu/kimo/publications/retrographic/sensor.pdf | 9999121 | 1fbbc83a62717036831e45edf28670c8f7d66572d4ad8976ae5be3e7d0097712 | Readable (8 pages)
10 | GelSight: High-Resolution Robot Tactile Sensors for Estimating Geometry and Force, | W. Yuan, S. Dong, and E. H. Adelson | 2017 | Chapter 2 Related Work / 2.2 Representative vision-based tactile sensors; Chapter 4 Hardware Design and Fabrication / 4.2 Camera, decoder board and LED PCB integration | https://doi.org/10.3390/s17122762 | 01_Thesis/Final/Dissertation_LIU Zhaolin.pdf | 04_Reference_Library/Files/REF_10_2017_GelSight_High_Resolution_Robot_Tactile_Sensors_for_Estimating_Geometry_and_Force.pdf | Downloaded and PDF-readable | Metadata checked against DOI/OpenAlex or the cited official source. Authoritative URL: https://doi.org/10.3390/s17122762. | GelSight: High-Resolution Robot Tactile Sensors for Estimating Geometry and Force | 2017 | Open access | Stanford CS114 course reading archive | https://web.stanford.edu/class/cs114/readings/MK-Yuan.pdf | 27442699 | e40e658db44c1f35d527e86ee104ee8e6f16da330bdf92c3cdd2d6a8f12ace91 | Readable (21 pages)
11 | Improved GelSight Tactile Sensor for Measuring Geometry and Slip, | S. Dong, W. Yuan, and E. H. Adelson | 2017 | Chapter 2 Related Work / 2.2 Representative vision-based tactile sensors | https://doi.org/10.1109/IROS.2017.8202149 | 01_Thesis/Final/Dissertation_LIU Zhaolin.pdf | Not included in portfolio; use DOI or source URL | Link only; redistribution permission not established | Metadata checked against DOI/OpenAlex or the cited official source. Authoritative URL: https://doi.org/10.1109/IROS.2017.8202149. | Improved GelSight tactile sensor for measuring geometry and slip | 2017 | Open access | OpenAlex best OA location | https://arxiv.org/pdf/1708.00922 | 5514379 | 9c27d57d760f895d2d90c8c287368ee90580f1f72b8be0d5d7016cd2aa207afb | Readable (8 pages)
12 | GelSlim: A High-Resolution, Compact, Robust, and Calibrated Tactile-Sensing Finger, | E. Donlon, S. Dong, M. Liu, J. Li, E. H. Adelson, and A. Rodriguez | 2018 | Chapter 2 Related Work / 2.2 Representative vision-based tactile sensors | https://doi.org/10.1109/IROS.2018.8593661 | 01_Thesis/Final/Dissertation_LIU Zhaolin.pdf | Not included in portfolio; use DOI or source URL | Link only; redistribution permission not established | Metadata checked against DOI/OpenAlex or the cited official source. Authoritative URL: https://doi.org/10.1109/IROS.2018.8593661. | GelSlim: A High-Resolution, Compact, Robust, and Calibrated Tactile-sensing Finger | 2018 | Open access | OpenAlex best OA location | https://arxiv.org/pdf/1803.00628 | 2515615 | e71d2ab201d4ef70b0b07478b4f51c10e68d32890d253ae08bd3cb0d691e0bb8 | Readable (8 pages)
13 | GelSlim 3.0: High-Resolution Measurement of Shape, Force and Slip in a Compact Tactile-Sensing Finger, | I. H. Taylor, S. Dong, and A. Rodriguez | 2022 | Chapter 2 Related Work / 2.2 Representative vision-based tactile sensors | https://doi.org/10.1109/ICRA46639.2022.9811832 | 01_Thesis/Final/Dissertation_LIU Zhaolin.pdf | Not included in portfolio; use DOI or source URL | Link only; redistribution permission not established | Metadata checked against DOI/OpenAlex or the cited official source. Authoritative URL: https://doi.org/10.1109/ICRA46639.2022.9811832. | GelSlim 3.0: High-Resolution Measurement of Shape, Force and Slip in a Compact Tactile-Sensing Finger | 2022 | Open access | arXiv | https://arxiv.org/pdf/2103.12269 | 10071789 | 8b7901959812b30324fa47e82a908cf781259ef7c59f41f2fce5b28c36a22cb1 | Readable (9 pages)
14 | DIGIT: A Novel Design for a Low-Cost Compact High-Resolution Tactile Sensor with Application to In-Hand Manipulation, | M. Lambeta et al. | 2020 | Chapter 2 Related Work / 2.2 Representative vision-based tactile sensors; Chapter 4 Hardware Design and Fabrication / 4.2 Camera, decoder board and LED PCB integration | https://doi.org/10.1109/LRA.2020.2977257 | 01_Thesis/Final/Dissertation_LIU Zhaolin.pdf | Not included in portfolio; use DOI or source URL | Link only; redistribution permission not established | Metadata checked against DOI/OpenAlex or the cited official source. Authoritative URL: https://doi.org/10.1109/LRA.2020.2977257. | DIGIT: A Novel Design for a Low-Cost Compact High-Resolution Tactile Sensor With Application to In-Hand Manipulation | 2020 | Open access | OpenAlex best OA location | https://arxiv.org/pdf/2005.14679 | 7098575 | dbcae130d003bcea9c4a61075458f3ea11597c60e029c18b88f254958fc97d14 | Readable (8 pages)
15 | The TacTip Family: Soft Optical Tactile Sensors with 3D-Printed Biomimetic Morphologies, | B. Ward-Cherrier et al. | 2018 | Chapter 2 Related Work / 2.2 Representative vision-based tactile sensors | https://doi.org/10.1089/soro.2017.0052 | 01_Thesis/Final/Dissertation_LIU Zhaolin.pdf | 04_Reference_Library/Files/REF_15_2018_The_TacTip_Family_Soft_Optical_Tactile_Sensors_with_3D_Printed_Biomimetic_Morpho.pdf | Downloaded and PDF-readable | Metadata checked against DOI/OpenAlex or the cited official source. Authoritative URL: https://doi.org/10.1089/soro.2017.0052. OpenAlex best OA location: HTTP Error 403: Forbidden | OpenAlex OA location: <urlopen error [SSL: UNEXPECTED_EOF_WHILE_READING] EOF occurred in violation of protocol (_ssl.c:1010)> | The TacTip Family: Soft Optical Tactile Sensors with 3D-Printed Biomimetic Morphologies | 2018 | Open access | OpenAlex OA location | https://research-information.bris.ac.uk/ws/files/142140217/Full_text_PDF_final_published_version_.pdf | 1378352 | b8314c9daeebeed66aa44595ca887f611dfdfd28fda3fe1fcc88d89bf3664c7b | Readable (13 pages)
16 | Combining Finger Vision and Optical Tactile Sensing: Reducing and Handling Errors while Cutting Vegetables, | A. Yamaguchi and C. G. Atkeson | 2016 | Chapter 2 Related Work / 2.2 Representative vision-based tactile sensors | https://doi.org/10.1109/HUMANOIDS.2016.7803400 | 01_Thesis/Final/Dissertation_LIU Zhaolin.pdf | Not archived; use authoritative URL | Unavailable after public-source checks | Metadata checked against DOI/OpenAlex or the cited official source. Authoritative URL: https://doi.org/10.1109/HUMANOIDS.2016.7803400. No public PDF URL found | Combining finger vision and optical tactile sensing: Reducing and handling errors while cutting vegetables | 2016 | Closed/metadata only |  |  |  |  | Not downloaded
17 | ReSkin: Versatile, Replaceable, Lasting Tactile Skins, | R. Bhirangi, T. Hellebrekers, C. Majidi, and A. Gupta | 2022 | Chapter 2 Related Work / 2.2 Representative vision-based tactile sensors |  | 01_Thesis/Final/Dissertation_LIU Zhaolin.pdf | Not included in portfolio; use DOI or source URL | Link only; redistribution permission not established | Metadata checked against DOI/OpenAlex or the cited official source. Authoritative URL: https://doi.org/10.48550/arxiv.2111.00071. | ReSkin: Versatile, Replaceable, Lasting Tactile Skins | 2021 | Open access | OpenAlex best OA location | https://arxiv.org/pdf/2111.00071 | 10198127 | b0897a9707c8e32d86856a13328e9197707c10570e12037f54a73d43833c98bd | Readable (11 pages)
18 | DTact: A Vision-Based Tactile Sensor that Measures High-Resolution 3D Geometry Directly from Darkness, | C. Lin, Z. Lin, S. Wang, and H. Xu | 2023 | Chapter 2 Related Work / 2.2 Representative vision-based tactile sensors | https://doi.org/10.1109/ICRA48891.2023.10160796 | 01_Thesis/Final/Dissertation_LIU Zhaolin.pdf | Not included in portfolio; use DOI or source URL | Link only; redistribution permission not established | Metadata checked against DOI/OpenAlex or the cited official source. Authoritative URL: https://doi.org/10.1109/ICRA48891.2023.10160796. | DTact: A Vision-Based Tactile Sensor that Measures High-Resolution 3D Geometry Directly from Darkness | 2023 | Open access | arXiv | https://arxiv.org/pdf/2209.13916 | 1785994 | 20d0ad3b2d6510dba9e9e7e95caf8790a858bd4ab2e3b2250b7969909818abef | Readable (8 pages)
19 | 9DTact: A Compact Vision-Based Tactile Sensor for Accurate 3D Shape Reconstruction and Generalizable 6D Force Estimation, | C. Lin, H. Zhang, J. Xu, L. Wu, and H. Xu | 2024 | Chapter 2 Related Work / 2.2 Representative vision-based tactile sensors; Chapter 2 Related Work / 2.3 Shape reconstruction and force estimation; Chapter 4 Hardware Design and Fabrication / 4.1 Adaptation from the original 9DTact design; Chapter 6 Six-Axis Force Platform and Transfer-Learning Study Design / 6.3 Transfer learning from the pretrained 9DTact model; Chapter 7 System Results, Gripper Integration and Discussion / 7.2 Engineering comparison with the original 9DTact | https://doi.org/10.1109/LRA.2023.3339397 | 01_Thesis/Final/Dissertation_LIU Zhaolin.pdf | Not included in portfolio; use DOI or source URL | Link only; redistribution permission not established | Metadata checked against DOI/OpenAlex or the cited official source. Authoritative URL: https://doi.org/10.1109/LRA.2023.3339397. | 9DTact: A Compact Vision-Based Tactile Sensor for Accurate 3D Shape Reconstruction and Generalizable 6D Force Estimation | 2023 | Open access | arXiv | https://arxiv.org/pdf/2308.14277 | 4267229 | 1ebc9a2baa86d5a4d5d48c692abb571d0a047db1881f10d20aae7503994065ac | Readable (8 pages)
20 | DelTact: A Vision-Based Tactile Sensor Using a Dense Color Pattern, | G. Zhang, Y. Du, H. Yu, and M. Y. Wang | 2022 | Chapter 2 Related Work / 2.2 Representative vision-based tactile sensors | https://doi.org/10.1109/LRA.2022.3196141 | 01_Thesis/Final/Dissertation_LIU Zhaolin.pdf | Not included in portfolio; use DOI or source URL | Link only; redistribution permission not established | Metadata checked against DOI/OpenAlex or the cited official source. Authoritative URL: https://doi.org/10.1109/LRA.2022.3196141. | DelTact: A Vision-Based Tactile Sensor Using a Dense Color Pattern | 2022 | Open access | arXiv | https://arxiv.org/pdf/2202.02179 | 1918779 | ce8c98829c93a40e9857955a73c9d3f8177c409515ddd50ff199916483083e7e | Readable (8 pages)
21 | DenseTact 2.0: Optical Tactile Sensor for Shape and Force Reconstruction, | W. K. Do, B. Jurewicz, and M. Kennedy | 2023 | Chapter 2 Related Work / 2.2 Representative vision-based tactile sensors | https://doi.org/10.1109/ICRA48891.2023.10161150 | 01_Thesis/Final/Dissertation_LIU Zhaolin.pdf | Not included in portfolio; use DOI or source URL | Link only; redistribution permission not established | Metadata checked against DOI/OpenAlex or the cited official source. Authoritative URL: https://doi.org/10.1109/ICRA48891.2023.10161150. | DenseTact 2.0: Optical Tactile Sensor for Shape and Force Reconstruction | 2023 | Open access | arXiv | https://arxiv.org/pdf/2209.10122 | 38167929 | f80a58d80cbd2dba1cd41d6738ae606127b234612fd1f4237db8b525d602f578 | Readable (7 pages)
22 | Photometric Method for Determining Surface Orientation from Multiple Images, | R. J. Woodham | 1980 | Chapter 2 Related Work / 2.3 Shape reconstruction and force estimation | https://doi.org/10.1117/12.7972479 | 01_Thesis/Final/Dissertation_LIU Zhaolin.pdf | Not archived; use authoritative URL | Unavailable after public-source checks | Metadata checked against DOI/OpenAlex or the cited official source. Authoritative URL: https://doi.org/10.1117/12.7972479. No public PDF URL found | Photometric Method For Determining Surface Orientation From Multiple Images | 1980 | Closed/metadata only |  |  |  |  | Not downloaded
23 | Dense Tactile Force Estimation Using GelSlim and Inverse FEM, | D. Ma, E. Donlon, S. Dong, and A. Rodriguez | 2019 | Chapter 2 Related Work / 2.3 Shape reconstruction and force estimation | https://doi.org/10.1109/ICRA.2019.8794113 | 01_Thesis/Final/Dissertation_LIU Zhaolin.pdf | Not included in portfolio; use DOI or source URL | Link only; redistribution permission not established | Metadata checked against DOI/OpenAlex or the cited official source. Authoritative URL: https://doi.org/10.1109/ICRA.2019.8794113. | Dense Tactile Force Estimation using GelSlim and inverse FEM | 2019 | Open access | Semantic Scholar open-access record | https://cf003.cdn.4science.cloud/4s-assetstore-prod--mit--dspace/129560235830064982905772194779168079914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 | 4350612 | a8591ac91391444ba5fcd27a06d7d59db4e424bf23344dfa82e3aaadda7984eb | Readable (7 pages)
24 | Effective Estimation of Contact Force and Torque for Vision-Based Tactile Sensors with Helmholtz–Hodge Decomposition, | Y. Zhang, Z. Kan, Y. Yang, Y. A. Tse, and M. Y. Wang | 2019 | Chapter 2 Related Work / 2.3 Shape reconstruction and force estimation | https://doi.org/10.1109/LRA.2019.2930477 | 01_Thesis/Final/Dissertation_LIU Zhaolin.pdf | Not included in portfolio; use DOI or source URL | Link only; redistribution permission not established | Metadata checked against DOI/OpenAlex or the cited official source. Authoritative URL: https://doi.org/10.1109/LRA.2019.2930477. | Effective Estimation of Contact Force and Torque for Vision-Based Tactile Sensors With Helmholtz–Hodge Decomposition | 2019 | Open access | arXiv | https://arxiv.org/pdf/1906.09460 | 4564062 | c72953d8b040360d6e266f1cb8e7c2819dc3cc694a5227615880aba91e982ba0 | Readable (8 pages)
25 | More Than a Feeling: Learning to Grasp and Regrasp Using Vision and Touch, | R. Calandra et al. | 2018 | Chapter 2 Related Work / 2.3 Shape reconstruction and force estimation | https://doi.org/10.1109/LRA.2018.2852779 | 01_Thesis/Final/Dissertation_LIU Zhaolin.pdf | Not included in portfolio; use DOI or source URL | Link only; redistribution permission not established | Metadata checked against DOI/OpenAlex or the cited official source. Authoritative URL: https://doi.org/10.1109/LRA.2018.2852779. | More Than a Feeling: Learning to Grasp and Regrasp Using Vision and Touch | 2018 | Open access | OpenAlex best OA location | https://arxiv.org/pdf/1805.11085 | 5331834 | d32d6ce83e6932a65b38301edb5f11913316ee7d0d917e9a3a37968d572596de | Readable (8 pages)
26 | Maintaining Grasps within Slipping Bounds by Monitoring Incipient Slip, | S. Dong, D. Ma, E. Donlon, and A. Rodriguez | 2019 | Chapter 2 Related Work / 2.3 Shape reconstruction and force estimation | https://doi.org/10.1109/ICRA.2019.8793538 | 01_Thesis/Final/Dissertation_LIU Zhaolin.pdf | Not archived; use authoritative URL | Unavailable after public-source checks | Metadata checked against DOI/OpenAlex or the cited official source. Authoritative URL: https://doi.org/10.1109/ICRA.2019.8793538. No public PDF URL found | Maintaining Grasps within Slipping Bounds by Monitoring Incipient Slip | 2019 | Closed/metadata only |  |  |  |  | Not downloaded
27 | Slip Detection for Grasp Stabilization with a Multifingered Tactile Robot Hand, | J. W. James and N. F. Lepora | 2021 | Chapter 2 Related Work / 2.3 Shape reconstruction and force estimation | https://doi.org/10.1109/TRO.2020.3031245 | 01_Thesis/Final/Dissertation_LIU Zhaolin.pdf | Not archived; use authoritative URL | Unavailable after public-source checks | Metadata checked against DOI/OpenAlex or the cited official source. Authoritative URL: https://doi.org/10.1109/TRO.2020.3031245. No public PDF URL found | Slip Detection for Grasp Stabilization With a Multifingered Tactile Robot Hand | 2020 | Closed/metadata only |  |  |  |  | Not downloaded
28 | Densely Connected Convolutional Networks, | G. Huang, Z. Liu, L. van der Maaten, and K. Q. Weinberger | 2017 | Chapter 6 Six-Axis Force Platform and Transfer-Learning Study Design / 6.3 Transfer learning from the pretrained 9DTact model | https://doi.org/10.1109/CVPR.2017.243 | 01_Thesis/Final/Dissertation_LIU Zhaolin.pdf | Not included in portfolio; use DOI or source URL | Link only; redistribution permission not established | Metadata checked against DOI/OpenAlex or the cited official source. Authoritative URL: https://doi.org/10.1109/CVPR.2017.243. | Densely Connected Convolutional Networks | 2017 | Open access | arXiv | https://arxiv.org/pdf/1608.06993 | 1142400 | b55aa1adbdf07f731daa84b94d23103d1eb22d1821a556b80212debee69b096d | Readable (9 pages)
29 | FT 300 Force Torque Sensor: Instruction Manual, | Robotiq Inc. | 2019 | Chapter 6 Six-Axis Force Platform and Transfer-Learning Study Design / 6.1 Customised sensor–FT300 experimental platform | https://assets.robotiq.com/website-assets/support_documents/document/FT_Sensor_Manual_general_PDF_20190625.pdf | 01_Thesis/Final/Dissertation_LIU Zhaolin.pdf | Not included in portfolio; use DOI or source URL | Link only; redistribution permission not established | Metadata checked against DOI/OpenAlex or the cited official source. Authoritative URL: https://assets.robotiq.com/website-assets/support_documents/document/FT_Sensor_Manual_general_PDF_20190625.pdf. Identity verified from the official Robotiq PDF title page; generic title-search metadata was discarded. | FT 300 Force Torque Sensor: Instruction Manual | 2019 | Official public manual | Official Robotiq manual | https://assets.robotiq.com/website-assets/support_documents/document/FT_Sensor_Manual_general_PDF_20190625.pdf | 1747554 | 18572555ede529f1e99b05a6a5a3ce4370c1eee1ca8186eb3e1a0b9ad35e36ea | Readable (58 pages)
30 | 9DTact: Official Open-Source Hardware, Software, Dataset and Pretrained Models. | C. Lin, H. Zhang, J. Xu, L. Wu, and H. Xu | TO CONFIRM | Chapter 4 Hardware Design and Fabrication / 4.1 Adaptation from the original 9DTact design; Chapter 5 Calibration and Shape Reconstruction / 5.1 Calibration challenge introduced by the new camera; Chapter 5 Calibration and Shape Reconstruction / 5.2 Manual 7×9 geometric calibration; Chapter 5 Calibration and Shape Reconstruction / 5.3 RBF rectification and sensing-region selection; Chapter 5 Calibration and Shape Reconstruction / 5.4 Sphere-based depth calibration; Chapter 5 Calibration and Shape Reconstruction / 5.5 Pixel-to-depth mapping and reconstruction method; Chapter 5 Calibration and Shape Reconstruction / 5.7 Discussion of calibration performance and limitations; Chapter 6 Six-Axis Force Platform and Transfer-Learning Study Design / 6.3 Transfer learning from the pretrained 9DTact model; Chapter 7 System Results, Gripper Integration and Discussion / 7.2 Engineering comparison with the original 9DTact | https://github.com/linchangyi1/9DTact | 01_Thesis/Final/Dissertation_LIU Zhaolin.pdf | 04_Reference_Library/Files/REF_30_9DTact_Official_Repository/ | Official repository metadata archived | Metadata checked against DOI/OpenAlex or the cited official source. Authoritative URL: https://github.com/linchangyi1/9DTact. Official project README and LICENSE archived; repository accessed as a source record. | 9DTact: Official Open-Source Hardware, Software, Dataset and Pretrained Models. | 2023 | Official public repository | Official GitHub repository | https://raw.githubusercontent.com/linchangyi1/9DTact/main/README.md | 11025 | afce7eb3aae32f8164916622219ebd0d2da2fc03060acefa127259c006c25705 | N/A (text source)
31 | Transfer learning for vision-based tactile sensing, | C. Sferrazza and R. D’Andrea | 2019 | Chapter 6 Six-Axis Force Platform and Transfer-Learning Study Design / 6.3 Transfer learning from the pretrained 9DTact model | https://doi.org/10.1109/IROS40897.2019.8967571 | 01_Thesis/Final/Dissertation_LIU Zhaolin.pdf | Not included in portfolio; use DOI or source URL | Link only; redistribution permission not established | Metadata checked against DOI/OpenAlex or the cited official source. Authoritative URL: https://doi.org/10.1109/IROS40897.2019.8967571. | Transfer learning for vision-based tactile sensing | 2019 | Open access | OpenAlex best OA location | https://arxiv.org/pdf/1812.03163 | 4559114 | de7c0740633b668aebb6e998c45e3dcdffc8da69cbb55fcf688c9abac4a938ac | Readable (7 pages)
32 | Deep Domain Adaptation Regression for Force Calibration of Optical Tactile Sensors, | Z. Chen, N. Ou, J. Jiang, and S. Luo | 2024 | Chapter 6 Six-Axis Force Platform and Transfer-Learning Study Design / 6.3 Transfer learning from the pretrained 9DTact model | https://doi.org/10.1109/IROS58592.2024.10801904 | 01_Thesis/Final/Dissertation_LIU Zhaolin.pdf | Not archived; use authoritative URL | Unavailable after public-source checks | Metadata checked against DOI/OpenAlex or the cited official source. Authoritative URL: https://doi.org/10.1109/IROS58592.2024.10801904. No public PDF URL found | Deep Domain Adaptation Regression for Force Calibration of Optical Tactile Sensors | 2024 | Closed/metadata only |  |  |  |  | Not downloaded
33 | TransForce: Transferable Force Prediction for Vision-Based Tactile Sensors with Sequential Image Translation, | Z. Chen, N. Ou, X. Zhang, and S. Luo | 2025 | Chapter 6 Six-Axis Force Platform and Transfer-Learning Study Design / 6.3 Transfer learning from the pretrained 9DTact model | https://doi.org/10.1109/ICRA55743.2025.11127381 | 01_Thesis/Final/Dissertation_LIU Zhaolin.pdf | Not archived; use authoritative URL | Unavailable after public-source checks | Metadata checked against DOI/OpenAlex or the cited official source. Authoritative URL: https://doi.org/10.1109/ICRA55743.2025.11127381. No public PDF URL found | TransForce: Transferable Force Prediction for Vision-Based Tactile Sensors with Sequential Image Translation | 2025 | Closed/metadata only |  |  |  |  | Not downloaded

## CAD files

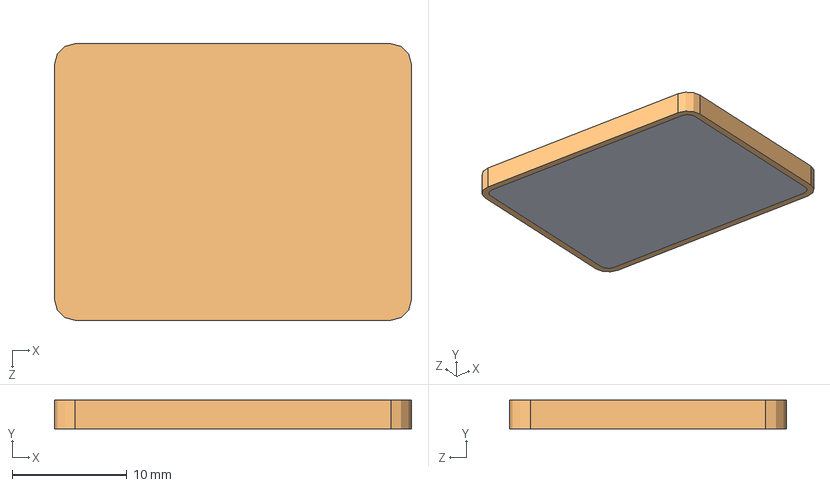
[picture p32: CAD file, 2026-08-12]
02_Software/Final_Repository_Snapshot/Original/9DTact_Design/3_Contact_Module/3_Contact_Module.SLDASM
31.1 x 2.50 x 24.1 mm
translucent_gel
black_gel

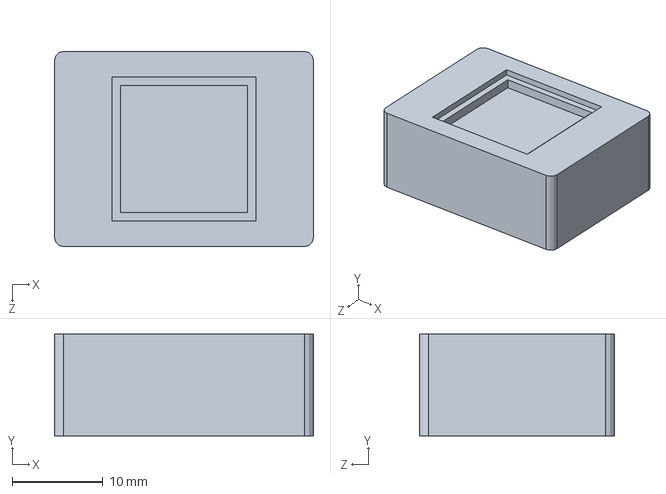
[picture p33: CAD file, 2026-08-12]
02_Software/Final_Repository_Snapshot/Original/9DTact_Design/2_Diffusion_Module/transparent_gel.SLDPRT
28.5 x 11.2 x 21.5 mm

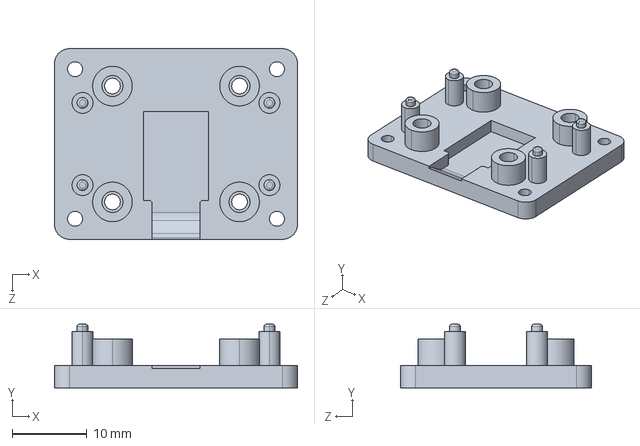
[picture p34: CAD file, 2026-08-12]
02_Software/Final_Repository_Snapshot/Original/9DTact_Design/fabrication/sensor_base.STEP
32.5 x 8.50 x 25.5 mm

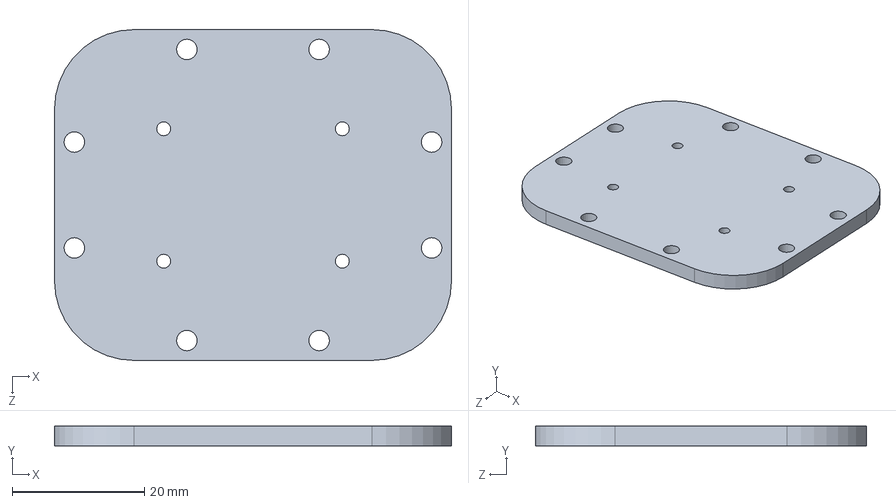
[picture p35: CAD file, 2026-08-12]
02_Software/Final_Repository_Snapshot/Original/9DTact_Design/mold/mold_base.SLDPRT
60.0 x 3.00 x 50.0 mm

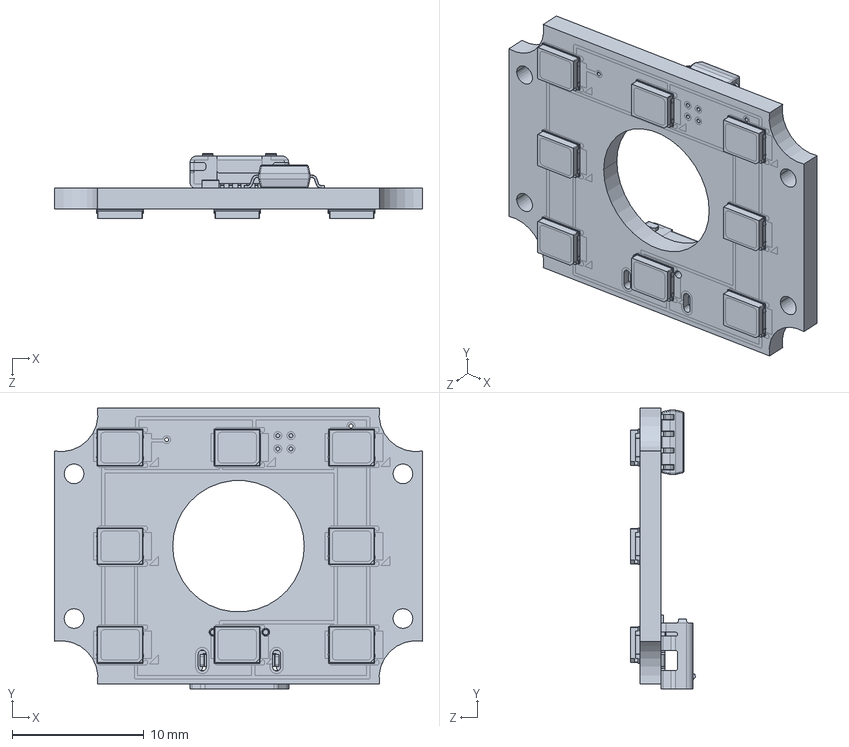
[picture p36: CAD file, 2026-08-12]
03_Hardware/01_CAD_Source/SolidWorks_Assemblies/LED_PCB_Model_from_JLC/led_board_from_JLC.SLDPRT
28.0 x 21.3 x 4.97 mm

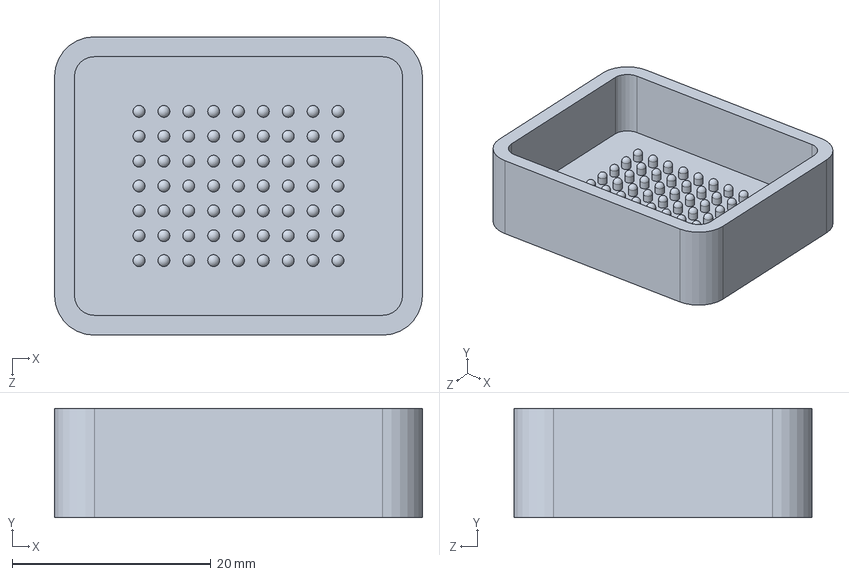
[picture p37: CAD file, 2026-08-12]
03_Hardware/01_CAD_Source/SolidWorks_Parts/Calibration/calibration_board.SLDPRT
37.0 x 11.0 x 30.0 mm

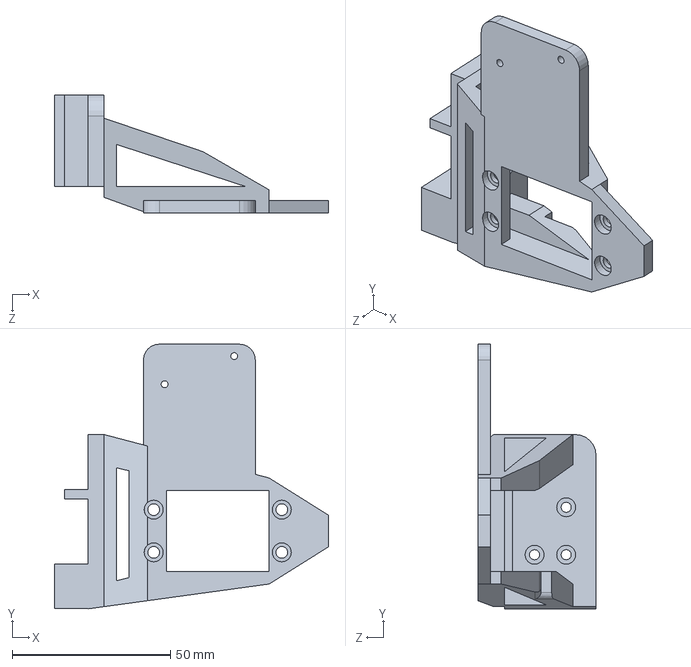
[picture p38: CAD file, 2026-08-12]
03_Hardware/01_CAD_Source/SolidWorks_Parts/Gripper/gripper-L.SLDPRT
86.6 x 83.7 x 37.3 mm

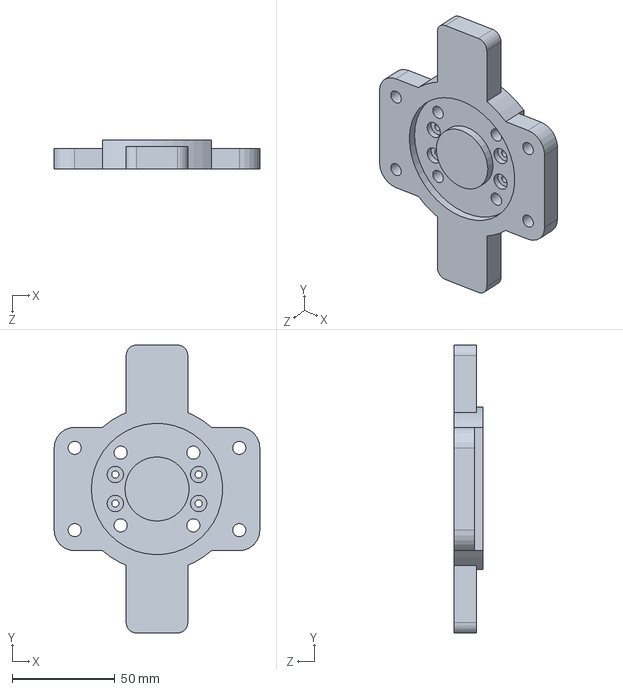
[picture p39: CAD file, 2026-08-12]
03_Hardware/01_CAD_Source/SolidWorks_Parts/Test_Connections/sensor_connection base.SLDPRT
100.0 x 140.0 x 14.0 mm

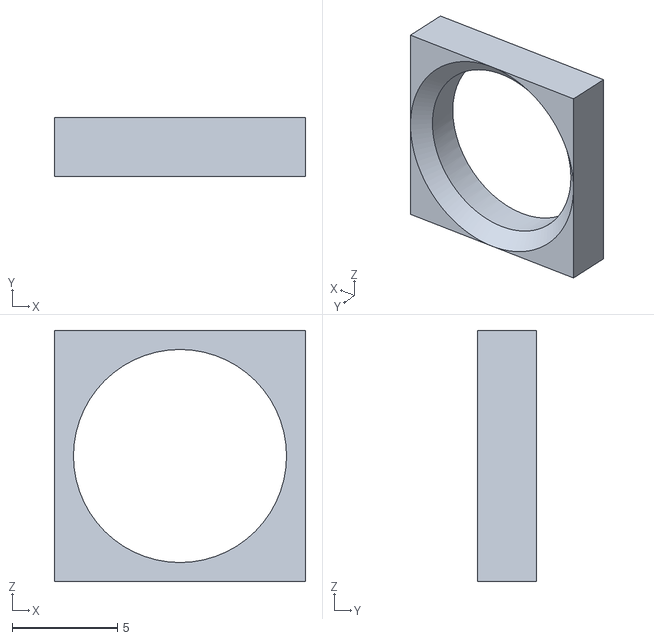
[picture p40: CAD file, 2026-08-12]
03_Hardware/03_Print_Files_STL/Converted/SolidWorks_Parts/Optimized_Sensor/isolation_ring.STL
11.9 x 2.80 x 11.9

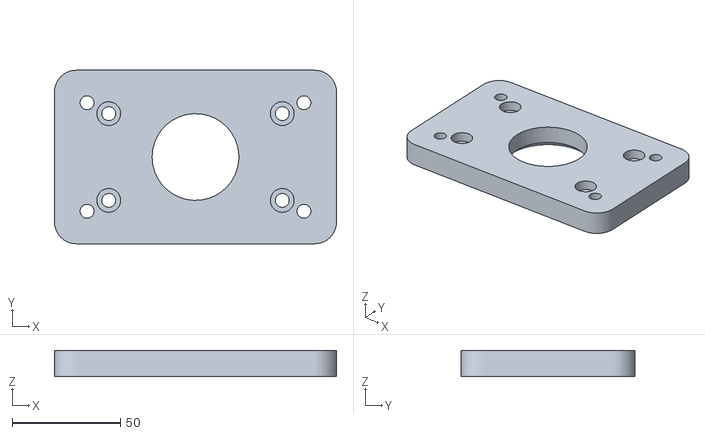
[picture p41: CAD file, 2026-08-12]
03_Hardware/03_Print_Files_STL/Converted/SolidWorks_Parts/Test_Connections/FT300_connection base.STL
130.0 x 80.0 x 12.0

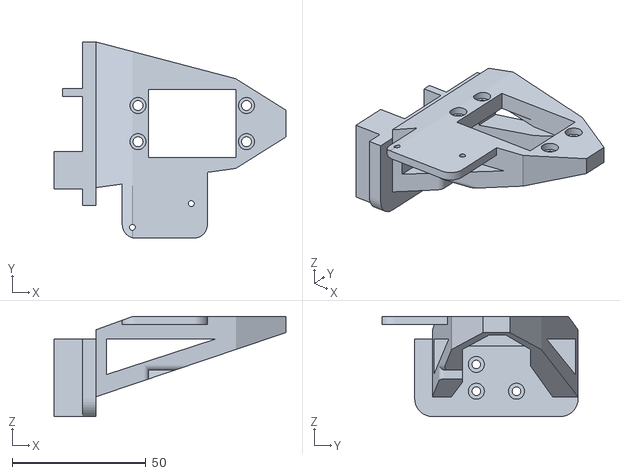
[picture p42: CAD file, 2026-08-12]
03_Hardware/03_Print_Files_STL/Existing_Source/Gripper/gripper-L.STL
86.6 x 73.2 x 37.4

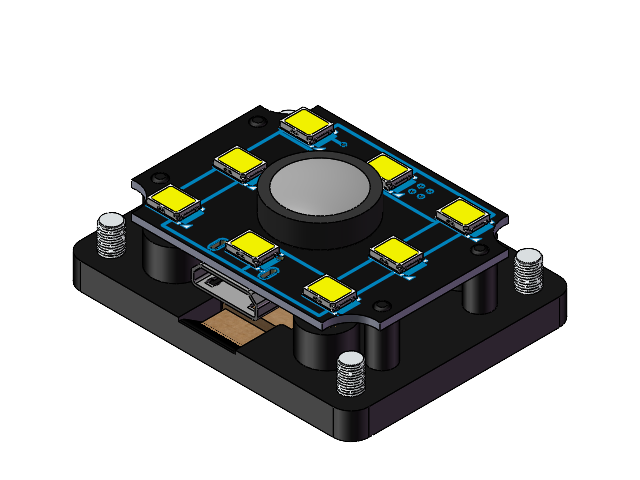
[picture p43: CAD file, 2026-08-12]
02_Software/Final_Repository_Snapshot/Original/9DTact_Design/1_Perception_Module/1_Perception_Module.SLDASM
sensor_base
camera(frank-s15-v1.0)
nut(2-3-5) x 4
led_board
screw(M2-5) x 4

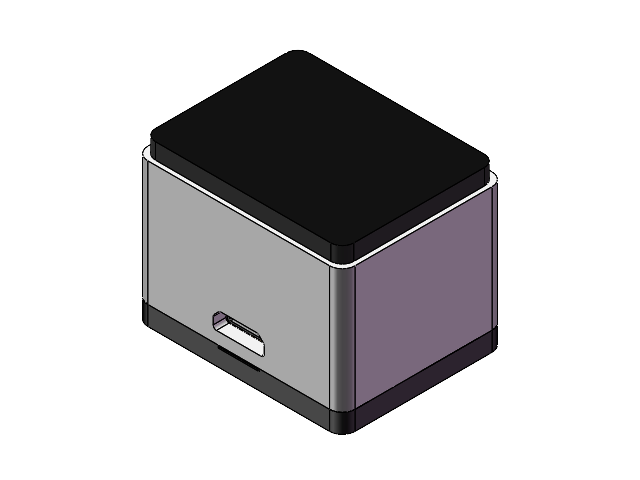
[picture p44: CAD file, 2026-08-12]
02_Software/Final_Repository_Snapshot/Original/9DTact_Design/9DTact.SLDASM
sensor_base
camera(frank-s15-v1.0)
nut(2-3-5) x 8
led_board
screw(M2-5) x 4
sensor_shell
acrylic_window
transparent_gel
isolation_ring
translucent_gel
black_gel

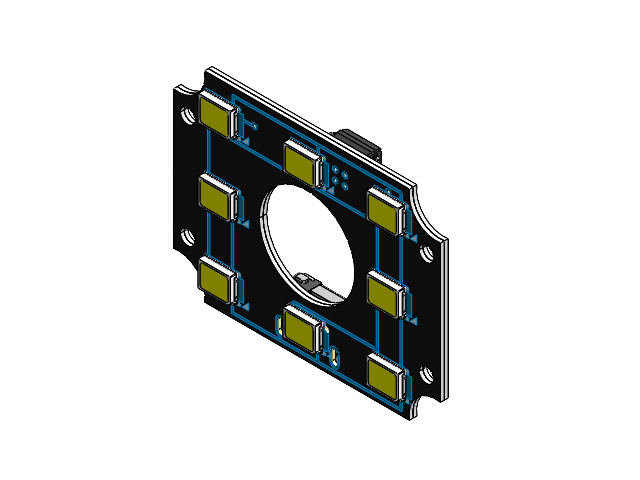
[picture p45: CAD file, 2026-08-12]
02_Software/Final_Repository_Snapshot/Original/9DTact_Design/LED_PCB/LED_Model_from_JLC/led_board_combined.SLDASM
led_board_down
led_board_up

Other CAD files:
02_Software/Final_Repository_Snapshot/Original/9DTact_Design/2_Diffusion_Module/2_Diffusion_Module.SLDASM
03_Hardware/01_CAD_Source/SolidWorks_Parts/Optimized_Sensor/sensor_base.SLDPRT
03_Hardware/03_Print_Files_STL/Converted/SolidWorks_Parts/Calibration/calibration_board.STL
02_Software/Final_Repository_Snapshot/Original/9DTact_Design/1_Perception_Module/camera(frank-s15-v1.0).SLDPRT
02_Software/Final_Repository_Snapshot/Original/9DTact_Design/1_Perception_Module/led_board.SLDPRT
02_Software/Final_Repository_Snapshot/Original/9DTact_Design/1_Perception_Module/nut(2-3-5).SLDPRT
02_Software/Final_Repository_Snapshot/Original/9DTact_Design/1_Perception_Module/screw(M2-5).SLDPRT
02_Software/Final_Repository_Snapshot/Original/9DTact_Design/1_Perception_Module/sensor_base.SLDPRT
02_Software/Final_Repository_Snapshot/Original/9DTact_Design/2_Diffusion_Module/acrylic_window.SLDPRT
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

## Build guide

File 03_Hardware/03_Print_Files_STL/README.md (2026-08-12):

# STL Print Files

Seven custom sensor, calibration and FT300 connection parts are paired with their native SolidWorks sources under `03_Hardware/01_CAD_Source/SolidWorks_Parts/`. Two gripper STL files remain under `Existing_Source/Gripper/`.

`STL_SOURCE_MAPPING.csv` records both file hashes, triangle counts and mesh checks. The seven imported files pass binary-length, finite-value, non-degenerate, single-component and closed 2-manifold checks. STL files do not encode units, so unit scale, fit, tolerances and printer settings must be confirmed against the native CAD and physical assembly before fabrication.

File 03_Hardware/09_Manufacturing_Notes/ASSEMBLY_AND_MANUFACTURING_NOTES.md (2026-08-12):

# Assembly and Manufacturing Notes

The authoritative assembly and fabrication description is in `01_Academic/01_Thesis/Final/Dissertation_LIU Zhaolin.pdf`, Chapter 4. The following is a navigation summary of the retained manufacturing evidence.

1. The camera, flexible cable, decoder board, and eight-LED PCB are integrated as the optical stack.
2. The enclosure provides camera seating, sensing-window support, cable clearance, and external mounting lugs.
3. The detachable mould supports staged casting of the recorded G50, G5, and G25 silicone layers.
4. Source records describe seam sealing, material mixing, vacuum degassing, casting, curing, demoulding, and final sensor assembly.
5. Each assembled sensor requires its own camera and sensor calibration records before use.

## Photograph evidence

The project photo catalog is `03_Hardware/08_Renders_and_Photos/PHOTO_CATALOG.md`. Original-to-delivery filename and SHA-256 traceability is recorded in `03_Hardware/08_Renders_and_Photos/PHOTO_SOURCE_MAPPING.csv`.

Manufacturing-process photographs are located in `03_Hardware/09_Manufacturing_Notes/Process_Photos/`:

1. `Process_Photos/printed_mold_and_housing_parts.jpg` records the printed mould and housing components.
2. `Process_Photos/mold_hot_glue_sealing.jpg` records seam sealing before casting.
3. `Process_Photos/silicone_material_preparation.jpg` and `Process_Photos/silicone_vacuum_degassing.jpg` record material preparation and degassing.
4. `Process_Photos/transparent_g50_bottom_layer.jpg`, `Process_Photos/translucent_g5_middle_layer.jpg`, and `Process_Photos/black_g25_top_layer.jpg` document the three recorded cured silicone layers.
5. `Process_Photos/multi_layer_casting_molds.jpg` records two assembled multi-layer moulds.

Assembly and integration evidence is located at:

- `03_Hardware/08_Renders_and_Photos/Completed_Hardware/completed_dual_custom_sensors.jpg`
- `03_Hardware/08_Renders_and_Photos/Assembly_and_Design/sensor_exploded_view_annotated.jpg`
- `03_Hardware/08_Renders_and_Photos/Assembly_and_Design/custom_gripper_assembly_render.png`
- `03_Hardware/08_Renders_and_Photos/Test_Setups/sensor_ft300_calibration_fixture.jpg`
- `03_Hardware/08_Renders_and_Photos/Test_Setups/benchtop_sensor_test_fixture.jpg`
- `03_Hardware/08_Renders_and_Photos/Test_Setups/screw_loading_sensor_test.jpg`

These photographs document the project's hardware integration and multi-stage manufacturing process.

## Seven supplied STL exports

The following seven binary STL files are present and structurally readable. Each is paired by base name with its preserved SolidWorks part; the STL files are delivery exports, while the `.SLDPRT` files remain the editable design sources.

| Native SolidWorks part | Supplied STL export |
|---|---|
| `03_Hardware/01_CAD_Source/SolidWorks_Parts/Calibration/calibration_board.SLDPRT` | `03_Hardware/03_Print_Files_STL/Converted/SolidWorks_Parts/Calibration/calibration_board.STL` |
| `03_Hardware/01_CAD_Source/SolidWorks_Parts/Optimized_Sensor/acrylic_window.SLDPRT` | `03_Hardware/03_Print_Files_STL/Converted/SolidWorks_Parts/Optimized_Sensor/acrylic_window.STL` |
| `03_Hardware/01_CAD_Source/SolidWorks_Parts/Optimized_Sensor/isolation_ring.SLDPRT` | `03_Hardware/03_Print_Files_STL/Converted/SolidWorks_Parts/Optimized_Sensor/isolation_ring.STL` |
| `03_Hardware/01_CAD_Source/SolidWorks_Parts/Optimized_Sensor/sensor_base.SLDPRT` | `03_Hardware/03_Print_Files_STL/Converted/SolidWorks_Parts/Optimized_Sensor/sensor_base.STL` |
| `03_Hardware/01_CAD_Source/SolidWorks_Parts/Optimized_Sensor/sensor_shell_optimized.SLDPRT` | `03_Hardware/03_Print_Files_STL/Converted/SolidWorks_Parts/Optimized_Sensor/sensor_shell_optimized.STL` |
| `03_Hardware/01_CAD_Source/SolidWorks_Parts/Test_Connections/FT300_connection base.SLDPRT` | `03_Hardware/03_Print_Files_STL/Converted/SolidWorks_Parts/Test_Connections/FT300_connection base.STL` |
| `03_Hardware/01_CAD_Source/SolidWorks_Parts/Test_Connections/sensor_connection base.SLDPRT` | `03_Hardware/03_Print_Files_STL/Converted/SolidWorks_Parts/Test_Connections/sensor_connection base.STL` |

Before fabrication, use the native SolidWorks geometry, project BOM, intended printer/material settings, and the actual mating hardware to confirm scale, orientation, support strategy, hole clearances, and fit. The original thesis figures and unmodified CAD/BOM files are the design authority.

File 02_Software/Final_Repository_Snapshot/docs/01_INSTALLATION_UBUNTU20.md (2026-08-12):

# 01 - Installation on Ubuntu 20.04

[Previous: Project overview](00_PROJECT_OVERVIEW.md) | [Home](../README.md) | [Next: Sensor configuration](02_SENSOR_CONFIGURATION.md)

## Baseline and dependency split

Use Ubuntu 20.04, Python 3.8, and ROS Noetic. Dependencies are intentionally divided:

| File or source | Purpose |
|---|---|
| `custom_9dtact/requirements-core.txt` | Camera calibration and shape reconstruction |
| `custom_9dtact/requirements-training.txt` | TensorBoard training support |
| `custom_9dtact/requirements-pytorch.txt` | PyTorch and torchvision versions |
| Ubuntu `apt` / ROS packages | `rospy`, messages, `cv_bridge`, `message_filters`, `ros_numpy`, catkin |
| External installation | FT300 ROS hardware driver |

`requirements.txt` is a convenience Python dependency entry point. For a controlled
installation, install the split files explicitly. Select a PyTorch CPU or CUDA wheel
source appropriate for the target computer; do not infer CUDA compatibility from this
repository.

## 1. Prepare Ubuntu and ROS Noetic

Install ROS Noetic using the official ROS 1 instructions for Ubuntu 20.04, then confirm:

```bash
source /opt/ros/noetic/setup.bash
rosversion -d
python3 --version
```

Expected results are `noetic` and Python 3.8.x. The bootstrap script checks these
conditions and stops on a mismatched distribution or Python version.

## 2. Run the core bootstrap

From the repository root:

```bash
cd <LOCAL_PROJECT_ROOT>
bash scripts/install_core_ubuntu20.sh
```

The script installs the core Ubuntu/ROS packages, creates
`custom_9dtact/.venv` with `--system-site-packages`, installs the pinned core Python
requirements, builds the catkin workspace, and runs dependency import checks. It does
not install an FT300 driver, open a camera, start ROS, run a CUDA workload, or test
hardware.

Activate the environment in each new terminal:

```bash
source /opt/ros/noetic/setup.bash
source <LOCAL_PROJECT_ROOT>/custom_9dtact/.venv/bin/activate
```

`--system-site-packages` is important because ROS Noetic Python modules are installed
by `apt` outside the virtual environment.

## 3. Verify core and ROS imports

```bash
cd <LOCAL_PROJECT_ROOT>
python scripts/verify_installation.py --profile core
python scripts/verify_installation.py --profile ros
```

These checks import dependencies and inspect required files. They do not contact
hardware or start a ROS master.

## 4. Add training dependencies when needed

Inside the activated virtual environment:

```bash
cd <LOCAL_PROJECT_ROOT>/custom_9dtact
python -m pip install -r requirements-training.txt
```

Install PyTorch from a wheel index that matches the target computer. CPU example:

```bash
python -m pip install -r requirements-pytorch.txt \
  --index-url https://download.pytorch.org/whl/cpu
```

For CUDA, first record the GPU model, driver version, and the wheel index selected for
PyTorch 2.0.1. Then verify:

```bash
cd <LOCAL_PROJECT_ROOT>
python scripts/verify_installation.py --profile training
python -c "import torch; print(torch.__version__); print(torch.cuda.is_available())"
```

A `False` CUDA result is valid for a CPU installation. Do not start a long training run
until a one- or two-epoch ResNet18 smoke test succeeds.

## 5. Build or rebuild the catkin workspace

```bash
source /opt/ros/noetic/setup.bash
cd <LOCAL_PROJECT_ROOT>/custom_9dtact/ros_ws
catkin_make
source devel/setup.bash
rospack find nine_dtact_ft300_ros
```

Repeat the `source devel/setup.bash` command in every terminal that launches this
package. Add it to a local shell profile only after the absolute workspace path is
stable.

## 6. Install the external FT300 driver

The repository does not contain a hardware driver. Select and install a driver that
works with the laboratory FT300/controller setup and that publishes
`geometry_msgs/WrenchStamped`. The project default topic is `/robotiq_ft_wrench`, but
the collector and launch files expose a configurable wrench-topic parameter.

After the driver is running, verify message type and samples:

```bash
rostopic type /robotiq_ft_wrench
rostopic hz /robotiq_ft_wrench
rostopic echo -n 1 /robotiq_ft_wrench

cd <LOCAL_PROJECT_ROOT>/custom_9dtact
python tools/check_ft300_topic.py --topic /robotiq_ft_wrench
```

Do not treat a package installation as proof that timestamps, frame, signs, units,
sample rate, zeroing, or hardware communication are correct.

## 7. Offline repository check

```bash
cd <LOCAL_PROJECT_ROOT>
python scripts/verify_submission.py
```

If an external `Original/` baseline manifest is available:

```bash
python scripts/verify_submission.py \
  --original-baseline <ORIGINAL_BASELINE_CSV>
```

## Common installation mistakes

- Using Python 3.12 instead of 3.8.
- Creating a virtual environment without `--system-site-packages`, which hides ROS
  Python packages.
- Installing a CUDA PyTorch wheel that does not match the driver.
- Copying a `.venv` or Conda environment between computers.
- Assuming the FT300 driver is included.
- Running a hardware program before sourcing both Noetic and the catkin workspace.
- Using a host-specific absolute path in configuration or documentation.

Continue with sensor selection only after core and ROS dependency checks pass.

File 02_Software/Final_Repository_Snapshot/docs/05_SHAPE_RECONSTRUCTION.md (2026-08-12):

# 05 - 3D Shape Reconstruction

[Previous: Sensor calibration](04_SENSOR_CALIBRATION.md) | [Home](../README.md) | [Next: FT300 setup](06_FT300_SETUP.md)

## Preconditions

Complete these steps for the selected sensor before opening the reconstruction program:

- confirm the Ubuntu camera channel with `v4l2-ctl`;
- activate the matching sensor templates;
- pass `tools/check_sensor_setup.py`;
- inspect the camera-calibration preview;
- record whether the active LUT is the hybrid official LUT or a custom LUT;
- remove all contact before establishing the reference surface.

The current image pipeline expects a `640 x 480` camera frame and produces a
`280 x 380` rectified crop for both sensor configurations.

## Sensor 1 procedure

```bash
cd <LOCAL_PROJECT_ROOT>/custom_9dtact
source .venv/bin/activate
python tools/activate_sensor.py --sensor-id 1
python tools/check_sensor_setup.py --sensor-id 1
cd shape_reconstruction
python _3_Shape_Reconstruction.py
```

## Sensor 2 procedure

Open a fresh terminal after stopping Sensor 1:

```bash
cd <LOCAL_PROJECT_ROOT>/custom_9dtact
source .venv/bin/activate
python tools/activate_sensor.py --sensor-id 2
python tools/check_sensor_setup.py --sensor-id 2
cd shape_reconstruction
python _3_Shape_Reconstruction.py
```

The program displays the rectified grayscale image, depth map, and Open3D point cloud.
Press `q` in the OpenCV window or close the Open3D visualizer to stop. Confirm that the
camera has been released before activating the other sensor.

## Required validation sequence

For each sensor, record the sensor ID, camera channel, active calibration hashes, date,
lighting, host, and operator. Then perform:

1. **No contact:** observe surface flatness, offset, noise, and drift for a fixed period.
2. **Light press:** confirm a small deformation appears at the physical contact point.
3. **Medium press:** confirm height changes continuously rather than jumping or
   reversing.
4. **Release:** confirm the reconstructed surface returns near its no-contact baseline.
5. **Location sweep:** press center, edges, and corners and compare real versus displayed
   contact location.
6. **Repeatability:** repeat a consistent press several times and compare response.

Do not describe light-press sensitivity as improved until measurements on the physical
sensor support that conclusion.

## Interpreting common symptoms

| Symptom | Likely checks |
|---|---|
| Camera does not open | Verify `/dev/videoX`, permissions, and competing processes |
| Output is rotated or mirrored | Recheck point order and physical orientation |
| Grid folds or crosses | Rebuild camera mapping; inspect manual preview before saving |
| Crop is incomplete | Confirm `crop_size: [280, 380]` and camera calibration |
| No-contact surface is uneven | Check reference image, lighting stability, camera mapping, and LUT |
| Contact position is wrong | Check row/column mapping and crop origin |
| Height sign or scale is implausible | Treat the active LUT as unvalidated and compare against a controlled backup |
| Sensor 1 and Sensor 2 look identical | Confirm active marker, configuration, camera, and calibration paths |

## Hybrid-LUT comparison

When comparing the official hybrid LUT with a custom LUT:

- change only the intended sensor's `Pixel_to_Depth.npy`;
- preserve that sensor's camera-mapping files;
- keep illumination and mechanical test conditions constant;
- hash and label every LUT;
- record results for Sensor 1 and Sensor 2 separately;
- restore from a verified backup rather than copying from the other sensor.

Running `_2_Sensor_Calibration.py` changes the active LUT and exits the current hybrid
state. If the official LUT is later restored for both sensors, rerun
`python tools/verify_hybrid_calibration.py`.

Proceed to FT300 setup only after standalone reconstruction is stable enough to capture
meaningful tactile images.

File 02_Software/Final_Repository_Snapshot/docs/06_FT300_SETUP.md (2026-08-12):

# 06 - FT300 Setup and Topic Validation

[Previous: Shape reconstruction](05_SHAPE_RECONSTRUCTION.md) | [Home](../README.md) | [Next: Data collection](07_DATA_COLLECTION.md)

## Role and software boundary

The FT300 supplies physical six-axis labels in the order
`Fx, Fy, Fz, Tx, Ty, Tz`. Force components use newtons and torque components use
newton-metres. It is used for supervised data acquisition and prediction validation.
It is not required for normal tactile-only neural inference after a model is trained.

The repository does not bundle an FT300 hardware driver. Install an external driver
appropriate for the laboratory controller and require it to publish
`geometry_msgs/WrenchStamped`. The project default topic is `/robotiq_ft_wrench`, but
the input topic is configurable.

No claim is made that a particular external driver is officially supported on ROS
Noetic. Driver/controller compatibility must be established on the target system.

## Mechanical and coordinate preparation

Before starting software:

- mount the FT300 and tactile sensor rigidly;
- record the FT300 serial/device identity and mounting orientation;
- define the tactile output frame;
- record the rotation and translation from the raw wrench frame to the tactile frame;
- check cable strain and ensure the unloaded system is mechanically stable;
- establish emergency-stop and load-limit procedures for the connected equipment.

The code can apply axis signs, a 3 x 3 rotation, and translation-induced torque. These
parameters must be derived from the real mounting geometry, not chosen to make plots
look convenient.

## Startup order for FT300 validation

Terminal 1 - ROS master:

```bash
source /opt/ros/noetic/setup.bash
roscore
```

Terminal 2 - external FT300 driver:

```bash
source /opt/ros/noetic/setup.bash
<START_EXTERNAL_FT300_DRIVER>
```

Terminal 3 - inspect the published interface:

```bash
source /opt/ros/noetic/setup.bash
rostopic type /robotiq_ft_wrench
rostopic hz /robotiq_ft_wrench
rostopic echo -n 1 /robotiq_ft_wrench
```

The required message type is exactly `geometry_msgs/WrenchStamped`. The header needs a
non-zero, recent timestamp and a non-empty, stable frame ID.

Run the repository checker:

```bash
cd <LOCAL_PROJECT_ROOT>/custom_9dtact
source .venv/bin/activate
python tools/check_ft300_topic.py \
  --topic /robotiq_ft_wrench \
  --samples 100 \
  --min-rate 10
```

If a specific frame is required, add `--expected-frame <FT300_FRAME>`. The check tests
message freshness, frame consistency, finite values, and observed header rate. It does
not establish calibration accuracy or mounting correctness.

## Zeroing and sign checks

1. Remove all external contact and allow the mounted system to settle.
2. Record mean and standard deviation before zeroing.
3. Apply the project's software-zero operation only while the system is unloaded.
4. Apply a gentle, known-direction load along each axis and verify the expected sign.
5. Apply a known lever-arm load to check torque signs and the translation transform.
6. Repeat the unloaded measurement to check drift.

Software zeroing removes the measured offset for that session. It does not calibrate
scale, compensate an incorrect transform, repair cross-axis coupling, or prove the
sensor is mounted correctly.

## Wrench ranges

The per-sensor force templates contain `wrench_min` and `wrench_max`. These ranges define
label validation, normalization, and conversion of network outputs back to physical
units. Review them against the safe experimental envelope before collecting data.

Samples outside the configured range can be rejected during processing. Never widen a
range solely to hide an incorrect sign, zero, unit, or transform.

## Shutdown order

After topic validation or acquisition:

1. stop recording and allow pending writes to finish;
2. stop the collector or comparison node;
3. stop the tactile camera publisher;
4. stop the external FT300 driver;
5. stop `roscore` last;
6. verify dataset files and copy the session to backup storage.

Use Ctrl+C once per terminal and wait for clean shutdown output before closing it.

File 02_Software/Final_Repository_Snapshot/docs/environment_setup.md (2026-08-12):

# Environment Setup Compatibility Note

This former page is retained only so older links remain valid. Follow the maintained
[Ubuntu 20.04 installation guide](01_INSTALLATION_UBUNTU20.md).

The target baseline is Ubuntu 20.04, Python 3.8, and ROS Noetic. Core, training,
PyTorch, ROS, and external FT300-driver dependencies are installed as separate layers.

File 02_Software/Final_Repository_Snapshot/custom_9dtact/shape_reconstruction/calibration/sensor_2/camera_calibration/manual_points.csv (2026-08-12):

index | row | col | x | y
1 | 1 | 1 | 126 | 88
2 | 1 | 2 | 178 | 94
3 | 1 | 3 | 227 | 96
4 | 1 | 4 | 274 | 101
5 | 1 | 5 | 320 | 105
6 | 1 | 6 | 369 | 100
7 | 1 | 7 | 418 | 93
8 | 1 | 8 | 473 | 88
9 | 1 | 9 | 520 | 85
10 | 2 | 1 | 130 | 144
11 | 2 | 2 | 184 | 145
12 | 2 | 3 | 232 | 147
13 | 2 | 4 | 276 | 151
14 | 2 | 5 | 319 | 151
15 | 2 | 6 | 364 | 150
16 | 2 | 7 | 411 | 146
17 | 2 | 8 | 465 | 142
18 | 2 | 9 | 516 | 139
19 | 3 | 1 | 133 | 187
20 | 3 | 2 | 184 | 192
21 | 3 | 3 | 234 | 193
22 | 3 | 4 | 279 | 194
23 | 3 | 5 | 320 | 195
24 | 3 | 6 | 362 | 195
25 | 3 | 7 | 409 | 192
26 | 3 | 8 | 462 | 188
27 | 3 | 9 | 514 | 187
28 | 4 | 1 | 132 | 236
29 | 4 | 2 | 185 | 236
30 | 4 | 3 | 234 | 240
31 | 4 | 4 | 278 | 239
32 | 4 | 5 | 319 | 237
33 | 4 | 6 | 362 | 236
34 | 4 | 7 | 408 | 239
35 | 4 | 8 | 459 | 239
36 | 4 | 9 | 514 | 237
37 | 5 | 1 | 129 | 283
38 | 5 | 2 | 183 | 283
39 | 5 | 3 | 232 | 283
40 | 5 | 4 | 278 | 281
41 | 5 | 5 | 319 | 279
42 | 5 | 6 | 363 | 279
43 | 5 | 7 | 408 | 282
44 | 5 | 8 | 464 | 286
45 | 5 | 9 | 521 | 289
46 | 6 | 1 | 121 | 336
47 | 6 | 2 | 178 | 331
48 | 6 | 3 | 229 | 329
49 | 6 | 4 | 277 | 325
50 | 6 | 5 | 319 | 323
51 | 6 | 6 | 365 | 325
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

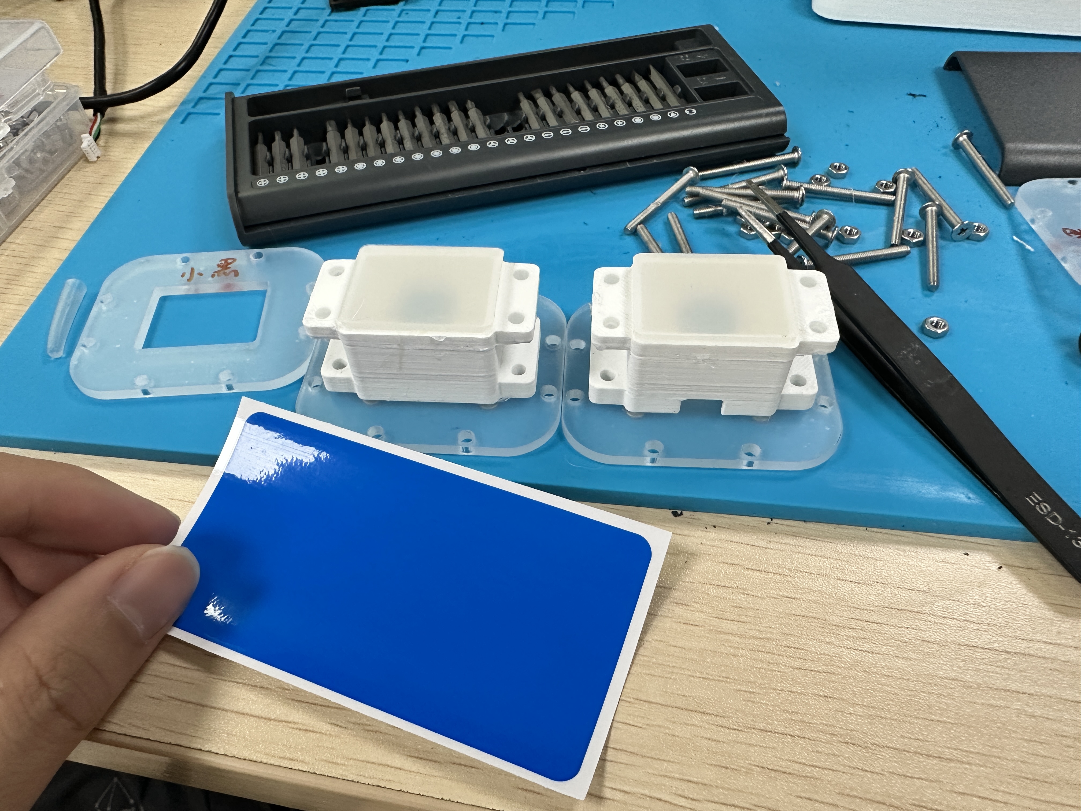
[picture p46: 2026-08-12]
03_Hardware/09_Manufacturing_Notes/Process_Photos/translucent_g5_middle_layer.jpg

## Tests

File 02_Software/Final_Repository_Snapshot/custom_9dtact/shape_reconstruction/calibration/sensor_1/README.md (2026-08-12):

# Sensor 1 标定目录

这里只能保存自制 Sensor 1 的标定结果。必须分别完成 Camera Calibration 和 Sensor Calibration；不得复制 Sensor 2 或原作者的标定文件。

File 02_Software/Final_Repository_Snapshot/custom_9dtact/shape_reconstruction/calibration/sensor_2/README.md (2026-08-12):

# Sensor 2 标定目录

这里只能保存自制 Sensor 2 的标定结果。必须分别完成 Camera Calibration 和 Sensor Calibration；不得复制 Sensor 1 或原作者的标定文件。

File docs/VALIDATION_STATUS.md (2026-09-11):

# 验证状态与技术边界

[返回首页](../README.md) · [贡献证据](PROJECT_OVERVIEW.md) · [版本来源](../VERSION_FREEZE.md)

核对日期：2026-09-11。以代码、活动数组、实物照片、实验记录和视频共同判断。历史材料没有记录的事项写为“当前仓库缺记录”，不据此认定从未做过。

## 四类证据

- **代码已实现**：有入口与相关逻辑，可做静态或离线检查。
- **有定性演示**：实物、界面或形貌响应可见，不能据此推导精度与实时性能。
- **有定量验证**：必须包含试验条件、原始数据、独立参考与可重算指标；本项目不对自定义力模型或形貌精度作此主张。
- **当前仓库缺记录**：证据链尚不能闭合，保留待补材料及相应表述边界。

## 六维力流程逐项区分

| 环节 | 已有证据 | 尚未闭合 |
|---|---|---|
| FT300 机械耦合与独立读数 | 转接 CAD、平台照片，论文 6.1/答辩第 14 页描述初步读数实验 | FT300 驱动版本、真实 topic/frame/rate 与完整运行日志 |
| FT300 无载软件置零 | 采集脚本及 `wrench.py` 实现，离线测试覆盖偏置处理 | 实机无载统计、漂移、预载和零点会话记录；不等于触觉力映射标定 |
| 坐标变换 | 旋转、轴符号及力矩原点位移处理代码 | 最终机械坐标、实测 R/t、轴向加载验证与变换记录 |
| 图像和六轴标签同步采集 | ApproximateTimeSynchronizer、三元组原子写入、数据完整性工具 | 最终自制传感器的规范同步训练数据集和 acquisition_sessions 记录 |
| 触觉图像到六维力映射标定/训练 | 数据拆分、归一化、ResNet/DenseNet 训练与推理入口 | 正式自制模型 checkpoint、训练日志、配套数据与模型配置 |
| 独立精度验证 | 有方法与实验设计说明 | 独立测试集、误差计算结果及测试条件；不报告 MAE/RMSE/R² 等数值 |
| 六轴向量视频 | 触觉按压与屏幕向量变化可见 | 模型、输入数据源、单位、标定版本与传感器编号未冻结；既不能当作 FT300 实测值证明，也不能当作自定义模型预测精度证明 |

上述代码位于 [FT300 采集](../02_Software/Final_Repository_Snapshot/custom_9dtact/data_collection/collect_data_ft300.py)、[wrench 工具](../02_Software/Final_Repository_Snapshot/custom_9dtact/force_estimation/wrench.py)、[训练](../02_Software/Final_Repository_Snapshot/custom_9dtact/force_estimation/train.py) 和 [推理](../02_Software/Final_Repository_Snapshot/custom_9dtact/force_estimation/_1_Force_Estimation.py)。正常推理路径使用触觉图像；FT300 用于标签和可选比较，两者不可混称。

## 相机与深度标定

手动相机标定脚本支持 7 × 9、共 63 点选择及 RBF 校正；保留了 Sensor 2 点选来源。对活动文件的哈希复核确认：Sensor 1 与 Sensor 2 的 `row_index.npy`、`col_index.npy`、`position_scale.npy` 逐字节相同。Sensor 1 缺独立点集来源，不能写成两套均有独立相机标定证据。

两个活动 `Pixel_to_Depth.npy` 都与 `Original/shape_reconstruction/calibration/sensor_1/depth_calibration/Pixel_to_Depth.npy` 相同，SHA-256 为 `19c9f3514dce402d8e710079757394b5445b74e7afbdd2459de43798676cb4ff`。这是保留的混合 LUT 实验配置。

论文与照片描述了球形压头及深度标定过程，螺纹重建提供定性结果；这些历史记录不能替代当前活动 LUT 的独立来源。没有对应到最终活动文件的独立深度误差测量、标定重复性或重装一致性记录。

快照内较早的局部 README 可能要求“不得复制标定”；当前实际冻结状态及例外由 [最终软件审查](../02_Software/Final_Repository_Snapshot/FINAL_AUDIT_REPORT.md) 和 [混合 LUT 实验记录](../02_Software/Final_Repository_Snapshot/docs/ORIGINAL_DEPTH_LUT_EXPERIMENT_2026-07-25.md) 解释，本次保留原文件，不追改历史软件说明。

## 机械、电气与制造限制

- 13 个原生 CAD 文件存在，但没有完整自定义传感器/夹爪 STEP 装配；原始 SolidWorks 创作版本、单位和重建状态尚未确认。
- 本次未对装配干涉、强度、疲劳、密封、寿命及制造公差做试验。9 个 STL 的结构检查不等于可制造性或尺寸验收。
- 制造照片和两套实物支持制作完成；缺最终逐步装配、端到端接线与统一供电参数，未形成经负责人核准的完整硬件说明。
- 夹爪仅有 CAD/STL 与渲染；当前没有实物抓取或触觉闭环控制证据。
- 缺按传感器编号和条件记录的结构化失败案例集；现有成功视频不代表覆盖全部工况。
- “约 30%”体积变化、R5 型号归属、原创 PCB 设计均不能由现有材料独立核实。

## 本次重新执行的检查

环境为 Windows、Python 3.12。项目运行基线仍为 Ubuntu 20.04 / Python 3.8 / ROS Noetic；测试依赖仅安装在仓库外的审查环境。

| 检查 | 本次结果 |
|---|---|
| `python -B -m unittest discover -s custom_9dtact/tests -v` | 30/30 通过；使用测试产生的临时样本，不代表真实采集数据 |
| `python -B scripts/verify_submission.py --strict-package` | 通过；包含 Python 语法、配置、XML、标定哈希与提交包检查 |
| 冻结软件比对 | 与整理前 Git 树一致；关联来源 297 个路径一致，90 个文件仅换行差异及相应内部清单差异，见版本说明 |
| 作品集链接与清单 | 使用仓库外检查程序校验路径、大小写、展示资源与 SHA-256 清单 |

没有运行硬件启动脚本、传感器切换写入、重新标定、真实同步采集、模型训练、CUDA 或 ROS master；没有进行 Ubuntu 实机验证或 SolidWorks 重建。冻结快照旧审查报告中的历史结果保留原日期，不冒充本次测试。

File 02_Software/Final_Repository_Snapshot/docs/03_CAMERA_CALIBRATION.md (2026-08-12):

# 03 - Camera Calibration

[Previous: Sensor configuration](02_SENSOR_CONFIGURATION.md) | [Home](../README.md) | [Next: Sensor calibration](04_SENSOR_CALIBRATION.md)

## Purpose and outputs

Camera calibration maps each raw `480 x 640` image to the sensor surface and defines
the physical crop. The active output directory for the selected sensor contains:

- `row_index.npy`, shape `(480, 640)`;
- `col_index.npy`, shape `(480, 640)`;
- `position_scale.npy`, shape `(3,)`;
- reference/sample images and optional manual-point provenance artifacts.

These files are sensor-specific. Never exchange them between Sensor 1 and Sensor 2.

## Provenance status in this delivery

- Sensor 2 includes manual-point provenance artifacts for its manual camera mapping.
- Sensor 1 active camera arrays are present, but independent source artifacts that
  reproduce their manual point selection are not present.

This distinction must remain visible in reports. An array passing shape and finiteness
checks does not by itself establish its point-selection history or physical quality.

## 1. Prepare the sensor

```bash
cd <LOCAL_PROJECT_ROOT>/custom_9dtact
python tools/activate_sensor.py --sensor-id 1
python tools/check_sensor_setup.py --sensor-id 1
v4l2-ctl --list-devices
```

Use Sensor 2 commands for the second device. Confirm the camera channel, focus,
lighting, grid target, and that no other process owns the camera.

Back up the selected sensor's entire active `camera_calibration/` directory outside the
repository before replacing outputs.

## 2. Automatic workflow

```bash
cd <LOCAL_PROJECT_ROOT>/custom_9dtact/shape_reconstruction
python _1_Camera_Calibration.py
```

Follow the program's image-capture and target-detection prompts. Review the produced
rectification and crop before accepting it. Automatic completion is not evidence of a
correct mapping if point detection is wrong.

## 3. Manual 7 x 9 workflow

The reviewed manual tool is:

`custom_9dtact/shape_reconstruction/manual_camera_calibration_v2.py`

Run it from the `shape_reconstruction` directory. To capture new averaged `ref.png`
and `sample.png` images before point selection:

```bash
python manual_camera_calibration_v2.py --capture
```

To use the existing images:

```bash
python manual_camera_calibration_v2.py
```

To resume an incomplete point-selection checkpoint:

```bash
python manual_camera_calibration_v2.py --resume
```

To start with local automatic snapping disabled:

```bash
python manual_camera_calibration_v2.py --no-snap
```

Optional capture and snapping controls are `--average-frames` and `--snap-radius`.
Use `python manual_camera_calibration_v2.py --help` for their current defaults.

### Point-selection order and controls

Click exactly 63 points in row-major order:

1. first row, left to right, 9 points;
2. second row, left to right, 9 points;
3. continue through the seventh row.

Controls:

| Input | Action |
|---|---|
| Left-click | Add the next point |
| Right-click or `U` | Undo the latest point |
| `R` | Clear all selected points |
| `A` | Toggle local snapping |
| Enter | Validate point order and open the preview |
| `B` in preview | Return to point selection |
| Lowercase `s` in preview | Save active outputs |
| `Q` or Escape | Exit without saving final outputs |

There is no implicit apply operation. The active arrays are replaced only when
lowercase `s` is pressed in the preview. Immediately before writing, the tool creates
a timestamped `manual_backup_YYYYMMDD_HHMMSS/` directory inside the active camera
calibration directory.

## 4. Preview and quality control

Before pressing lowercase `s`, inspect both preview windows:

- all horizontal and vertical grid lines are ordered and do not cross;
- the rectified crop contains the full useful contact area;
- border behavior does not fold or repeat image regions;
- the crop orientation matches the physical sensor orientation;
- the grid center and millimetres-per-pixel value are plausible;
- no obvious point is on the wrong dot or row;
- the reported outside-boundary mapping ratio is acceptable for the intended crop.

If any check fails, press `B`, undo points, and correct the map. Do not save merely
because the script generated an array.

## 5. Verify saved outputs

```bash
cd <LOCAL_PROJECT_ROOT>/custom_9dtact
python tools/check_sensor_setup.py --sensor-id 1
python tools/verify_hybrid_calibration.py
```

The second command also loads the camera arrays and checks their required shapes. Then
run the physical shape test described in
[Shape reconstruction](05_SHAPE_RECONSTRUCTION.md). Keep preview images, point files,
sensor ID, date, camera channel, and operator notes with the experiment record.

## Rollback

Stop all programs using the camera. Restore all three arrays from the same timestamped
backup for the same sensor, then rerun the static checks and physical preview. Never
restore only one of the three arrays and never use the other sensor's backup.

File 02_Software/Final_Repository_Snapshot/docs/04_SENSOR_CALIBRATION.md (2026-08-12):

# 04 - Sensor and Depth Calibration

[Previous: Camera calibration](03_CAMERA_CALIBRATION.md) | [Home](../README.md) | [Next: Shape reconstruction](05_SHAPE_RECONSTRUCTION.md)

## Two different calibration layers

Camera calibration creates the geometric mapping arrays. Sensor/depth calibration
creates `Pixel_to_Depth.npy`, which maps image response to reconstructed depth. Passing
camera calibration does not prove the depth LUT is accurate, and a valid LUT file does
not prove the camera mapping is correct.

## Current experimental hybrid state

Both active sensors currently use a byte-identical copy of:

`Original/shape_reconstruction/calibration/sensor_1/depth_calibration/Pixel_to_Depth.npy`

Expected SHA-256:

`19C9F3514DCE402D8E710079757394B5445B74E7AFBDD2459DE43798676CB4FF`

The source array has shape `(61,)`, minimum `-0.9467841221106313`, and maximum
`1.9151455666508503`. Sensor 1 and Sensor 2 retain sensor-specific active camera paths;
the current three core camera arrays are byte-identical between those paths.

This is an experimental hybrid depth-LUT configuration. It is useful for a controlled
response comparison, but it is not an independent, precise depth calibration of either
custom sensor. Optical material, illumination, camera response, elastomer geometry,
and contact mechanics can differ from the upstream device.

## Verify the hybrid state

```bash
cd <LOCAL_PROJECT_ROOT>/custom_9dtact
python tools/verify_hybrid_calibration.py
```

The script confirms that:

- the selected upstream LUT is uniquely resolved from `Original/` configuration;
- both active LUT hashes match the selected source;
- all arrays load and contain finite values;
- camera-array and LUT shapes meet structural requirements.

It does not touch a camera and does not prove physical response or depth accuracy.

## Creating a new sensor-specific LUT

Only begin a new depth experiment after camera calibration has been accepted and the
current LUT is backed up outside the repository. Activate exactly one sensor:

```bash
cd <LOCAL_PROJECT_ROOT>/custom_9dtact
python tools/activate_sensor.py --sensor-id 1
python tools/check_sensor_setup.py --sensor-id 1
cd shape_reconstruction
python _2_Sensor_Calibration.py
```

`_2_Sensor_Calibration.py` trains and replaces the active sensor's
`Pixel_to_Depth.npy`. Therefore this command intentionally exits the official hybrid
LUT state for that sensor. Record the source images, ball radius, illumination,
configuration, date, operator, generated hash, and validation results.

Do not run `verify_hybrid_calibration.py` expecting it to pass immediately after a new
custom LUT is generated; the active LUT is supposed to differ. If the experiment later
returns to the official hybrid state, restore the correct official LUT copy and rerun
the verifier.

## Required physical validation

For each sensor separately, use the standalone reconstruction workflow and record:

- no-contact surface flatness and temporal noise;
- whether a light press is visible;
- whether medium-press height increases continuously;
- saturation, sign reversal, or discontinuity;
- release recovery and baseline drift;
- whether the reconstructed contact location matches the real location;
- repeatability at several positions and over repeated presses.

The hybrid LUT may perform differently on the two custom sensors even though the file
is identical. Accept or reject it per sensor, not as a pair.

## Rollback choices

### Return to a backed-up custom LUT

Copy only the matching sensor's external backup into that sensor's
`depth_calibration/Pixel_to_Depth.npy`, calculate its SHA-256, run the static setup
check, and repeat physical reconstruction. This is no longer the official hybrid
state.

### Return to the official hybrid state

Copy the selected upstream Sensor 1 LUT into the chosen sensor's active depth directory
without changing any camera arrays. Then run:

```bash
cd <LOCAL_PROJECT_ROOT>/custom_9dtact
python tools/verify_hybrid_calibration.py
```

The verifier passes only when both active sensors match the official selected source.
See the detailed experiment record in
[ORIGINAL_DEPTH_LUT_EXPERIMENT_2026-07-25.md](ORIGINAL_DEPTH_LUT_EXPERIMENT_2026-07-25.md).

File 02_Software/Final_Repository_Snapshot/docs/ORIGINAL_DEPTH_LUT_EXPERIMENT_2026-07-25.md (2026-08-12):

# Official Depth-LUT Hybrid Calibration Experiment

[Home](../README.md) | [Sensor calibration guide](04_SENSOR_CALIBRATION.md) | [Shape validation](05_SHAPE_RECONSTRUCTION.md)

## Background

The two custom tactile-sensor paths already contained active camera-mapping and depth
files. The custom depth response was considered insufficiently sensitive for a light
press, so this controlled experiment copied one selected upstream 9DTact
`Pixel_to_Depth.npy` into both custom active depth paths while leaving the camera paths
untouched.

The purpose is to compare physical response on real hardware. A matching file hash and
a successful static check do not show that light-press response improved, that shape
reconstruction passed, or that the resulting depth estimate is accurate.

## How the upstream source was selected

Two filename candidates exist under the protected `Original/` snapshot:

| Candidate | Bytes | Shape | SHA-256 |
|---|---:|---:|---|
| `Original/shape_reconstruction/calibration/sensor_1/depth_calibration/Pixel_to_Depth.npy` | 616 | `(61,)` | `19C9F3514DCE402D8E710079757394B5445B74E7AFBDD2459DE43798676CB4FF` |
| `Original/shape_reconstruction/calibration/sensor_2/depth_calibration/Pixel_to_Depth.npy` | 568 | `(55,)` | `D84DE22E2ACB5E77BCC1D12F28BD42812FBD93BDEAB43C27314C0A951A82181B` |

`Original/shape_reconstruction/shape_config.yaml` declares `sensor_id: 1`, points its
calibration root to `../shape_reconstruction/calibration`, and names
`/depth_calibration/Pixel_to_Depth.npy`. Therefore the configuration resolves the
upstream runtime LUT to the Sensor 1 candidate. The experiment uses that file rather
than selecting a candidate by timestamp or size.

Selected-source numerical record:

- shape: `(61,)`;
- minimum: `-0.9467841221106313`;
- maximum: `1.9151455666508503`;
- all values finite;
- maximum greater than zero;
- SHA-256:
  `19C9F3514DCE402D8E710079757394B5445B74E7AFBDD2459DE43798676CB4FF`.

`Original/` remains byte-preserved and read-only.

## Changed active files

Replacement date recorded by the original experiment: 2026-07-26.

Only these active binary files were replaced:

1. `custom_9dtact/shape_reconstruction/calibration/sensor_1/depth_calibration/Pixel_to_Depth.npy`
2. `custom_9dtact/shape_reconstruction/calibration/sensor_2/depth_calibration/Pixel_to_Depth.npy`

Both target files are expected to have the selected-source SHA-256 above.

No upstream camera array, camera directory, reference/sample image, crop setting,
camera channel, reconstruction algorithm, sensor gray-to-depth logic, neural network,
loss function, or training algorithm was copied as part of this experiment.

## Camera-path protection and provenance

The active camera files remain under sensor-specific paths:

```text
custom_9dtact/shape_reconstruction/calibration/sensor_1/camera_calibration/
custom_9dtact/shape_reconstruction/calibration/sensor_2/camera_calibration/
```

Each contains `row_index.npy`, `col_index.npy`, and `position_scale.npy`. The current
core arrays in the two paths are byte-identical. This experiment did not change them,
but byte identity does not establish that the two devices were independently mapped.
Sensor 2 includes manual-point provenance artifacts; Sensor 1 lacks independent
manual-point source artifacts in this delivery.

The experiment's protection condition is that each sensor-specific path remains
unchanged across the LUT replacement. It does not require or imply distinct camera
array contents.

## Experimental status and risks

The resulting arrangement is:

- Sensor 1 sensor-specific active camera path plus the selected upstream Sensor 1 LUT;
- Sensor 2 sensor-specific active camera path plus the same selected upstream Sensor 1
  LUT.

This is an experimental hybrid calibration and must not be reported as an independent,
precise depth calibration of either custom sensor.

Principal risks include:

- mismatch in elastomer, optics, illumination, geometry, or camera response;
- offset, curvature, or noise in the no-contact surface;
- incorrect height scale, sign, saturation, or discontinuity;
- unchanged or worse light-press visibility;
- different physical behavior between the custom sensors despite an identical LUT;
- misleading conclusions if camera mapping, reference capture, and LUT response are not
  evaluated separately.

## Static verification

```bash
cd <LOCAL_PROJECT_ROOT>/custom_9dtact
python tools/verify_hybrid_calibration.py
```

The verifier checks source resolution, hashes, NumPy loading, finiteness, and required
array shapes. It does not open a camera, run Shape Reconstruction, access FT300, or
start ROS.

## Ubuntu 20.04 hardware validation

Test one sensor at a time.

### Sensor 1

```bash
cd <LOCAL_PROJECT_ROOT>/custom_9dtact
conda activate 9dtact
python tools/activate_sensor.py --sensor-id 1
python tools/check_sensor_setup.py --sensor-id 1
cd shape_reconstruction
python _3_Shape_Reconstruction.py
```

### Sensor 2

```bash
cd <LOCAL_PROJECT_ROOT>/custom_9dtact
conda activate 9dtact
python tools/activate_sensor.py --sensor-id 2
python tools/check_sensor_setup.py --sensor-id 2
cd shape_reconstruction
python _3_Shape_Reconstruction.py
```

For each sensor, record:

- no-contact surface flatness and noise;
- light-press visibility;
- continuity of height under a medium press;
- recovery after release;
- correctness of contact location;
- repeatability across positions and repeated contacts.

Only evidence from both physical sensors can support retaining the hybrid arrangement.

## Leaving the hybrid state intentionally

After selecting a sensor, running:

```bash
cd <LOCAL_PROJECT_ROOT>/custom_9dtact/shape_reconstruction
python _2_Sensor_Calibration.py
```

trains and replaces that active sensor's `Pixel_to_Depth.npy`. This intentionally exits
the official hybrid-LUT state. Back up the active LUT before running it and record the
new file's provenance and hash.

## Rollback

Before the original replacement, the custom LUTs were intended to be stored outside
the repository as:

- `Sensor1_Pixel_to_Depth_custom_before_original_lut.npy`;
- `Sensor2_Pixel_to_Depth_custom_before_original_lut.npy`.

Restore only the backup belonging to the same sensor:

```bash
cp <PROJECT_EXTERNAL_BACKUP_DIR>/Sensor1_Pixel_to_Depth_custom_before_original_lut.npy \
  <LOCAL_PROJECT_ROOT>/custom_9dtact/shape_reconstruction/calibration/sensor_1/depth_calibration/Pixel_to_Depth.npy

cp <PROJECT_EXTERNAL_BACKUP_DIR>/Sensor2_Pixel_to_Depth_custom_before_original_lut.npy \
  <LOCAL_PROJECT_ROOT>/custom_9dtact/shape_reconstruction/calibration/sensor_2/depth_calibration/Pixel_to_Depth.npy
```

Calculate hashes, run each sensor's setup check, and repeat the physical shape test.
Do not change camera arrays during LUT rollback.

To restore the official hybrid experiment instead, copy the selected upstream Sensor 1
LUT to both active depth paths and rerun `tools/verify_hybrid_calibration.py`. A passing
result confirms the file state only; physical revalidation is still required.

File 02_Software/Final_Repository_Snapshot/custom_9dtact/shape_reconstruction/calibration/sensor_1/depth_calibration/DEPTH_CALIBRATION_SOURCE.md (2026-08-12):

# Sensor 1 深度标定来源说明

## 当前活动文件

- 文件：`Pixel_to_Depth.npy`
- 替换日期：2026-07-26
- 来源：官方 `Original` 9DTact 项目的深度查找表
- 官方源文件项目内相对路径：`Original/shape_reconstruction/calibration/sensor_1/depth_calibration/Pixel_to_Depth.npy`
- 官方源文件 SHA-256：`19C9F3514DCE402D8E710079757394B5445B74E7AFBDD2459DE43798676CB4FF`
- 当前目标文件 SHA-256：`19C9F3514DCE402D8E710079757394B5445B74E7AFBDD2459DE43798676CB4FF`

## 标定边界

Sensor 1 仍使用 Sensor 1 自己的 Camera Calibration，包括其 `row_index.npy`、`col_index.npy` 和 `position_scale.npy`。本次没有从官方项目或 Sensor 2 复制任何 Camera Calibration 文件。

当前配置是“自制 Sensor 1 Camera Calibration + 官方 9DTact `Pixel_to_Depth.npy`”的实验性混合标定方案。它不等于已经对自制 Sensor 1 完成准确的深度标定，也不能据此声称形状重建精度或轻压灵敏度已经改善。

## 验证与回滚

Windows 环境只能进行文件、哈希和 NumPy 静态检查。必须回到 Ubuntu 20.04，连接 Sensor 1 真实硬件后运行 Shape Reconstruction，检查无接触平整度、轻压响应、连续增高、松开恢复和按压位置。

如果实际效果变差或出现异常，应停止实验，并从项目外部的修改前备份目录恢复 `Sensor1_Pixel_to_Depth_custom_before_original_lut.npy`，覆盖当前 Sensor 1 的 `Pixel_to_Depth.npy`。回滚时不得改动 Sensor 1 的 Camera Calibration。

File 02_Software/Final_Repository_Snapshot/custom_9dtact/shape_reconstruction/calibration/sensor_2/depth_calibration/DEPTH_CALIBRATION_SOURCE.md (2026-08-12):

# Sensor 2 深度标定来源说明

## 当前活动文件

- 文件：`Pixel_to_Depth.npy`
- 替换日期：2026-07-26
- 来源：官方 `Original` 9DTact 项目的深度查找表
- 官方源文件项目内相对路径：`Original/shape_reconstruction/calibration/sensor_1/depth_calibration/Pixel_to_Depth.npy`
- 官方源文件 SHA-256：`19C9F3514DCE402D8E710079757394B5445B74E7AFBDD2459DE43798676CB4FF`
- 当前目标文件 SHA-256：`19C9F3514DCE402D8E710079757394B5445B74E7AFBDD2459DE43798676CB4FF`

## 标定边界

Sensor 2 仍使用 Sensor 2 自己的 Camera Calibration，包括其 `row_index.npy`、`col_index.npy` 和 `position_scale.npy`。本次没有从官方项目或 Sensor 1 复制任何 Camera Calibration 文件。

当前配置是“自制 Sensor 2 Camera Calibration + 官方 9DTact `Pixel_to_Depth.npy`”的实验性混合标定方案。它不等于已经对自制 Sensor 2 完成准确的深度标定，也不能据此声称形状重建精度或轻压灵敏度已经改善。

## 验证与回滚

Windows 环境只能进行文件、哈希和 NumPy 静态检查。必须回到 Ubuntu 20.04，连接 Sensor 2 真实硬件后运行 Shape Reconstruction，检查无接触平整度、轻压响应、连续增高、松开恢复和按压位置。

如果实际效果变差或出现异常，应停止实验，并从项目外部的修改前备份目录恢复 `Sensor2_Pixel_to_Depth_custom_before_original_lut.npy`，覆盖当前 Sensor 2 的 `Pixel_to_Depth.npy`。回滚时不得改动 Sensor 2 的 Camera Calibration。

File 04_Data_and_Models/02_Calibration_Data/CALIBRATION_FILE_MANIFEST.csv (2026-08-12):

relative_path | sensor_id | size | sha256 | array_shape | array_dtype | all_finite
02_Software/Final_Repository_Snapshot/custom_9dtact/shape_reconstruction/calibration/sensor_1/camera_calibration/col_index.npy | 1 | 1228928 | f3f22ccf78d15431d178ac6fabb66b44c5a390b3354fb8f485f2533f05737982 | 480x640 | int32 | True
02_Software/Final_Repository_Snapshot/custom_9dtact/shape_reconstruction/calibration/sensor_1/camera_calibration/position_scale.npy | 1 | 152 | 15c95bf85f6da828832e20ee64da0d195427f11f96918b1795b6a3288326c118 | 3 | float64 | True
02_Software/Final_Repository_Snapshot/custom_9dtact/shape_reconstruction/calibration/sensor_1/camera_calibration/row_index.npy | 1 | 1228928 | f54090298f15e1e706256368d4b3e4308eecae751d241664b082fd61abf8c9aa | 480x640 | int32 | True
02_Software/Final_Repository_Snapshot/custom_9dtact/shape_reconstruction/calibration/sensor_1/depth_calibration/DEPTH_CALIBRATION_SOURCE.md | 1 | 1539 | d28fe19ca8cb3149b103254e6da9672c5919cef7241e898b3f833c7d28d8cdbd
02_Software/Final_Repository_Snapshot/custom_9dtact/shape_reconstruction/calibration/sensor_1/depth_calibration/Pixel_to_Depth.npy | 1 | 616 | 19c9f3514dce402d8e710079757394b5445b74e7afbdd2459de43798676cb4ff | 61 | float64 | True
02_Software/Final_Repository_Snapshot/custom_9dtact/shape_reconstruction/calibration/sensor_1/depth_calibration/rectify_crop_ref.png | 1 | 50937 | f222c51b6a2c59f471ecf46987dd595e45f5e9f54794316fff4247d066a5b916
02_Software/Final_Repository_Snapshot/custom_9dtact/shape_reconstruction/calibration/sensor_1/depth_calibration/rectify_crop_sample.png | 1 | 58021 | f5b5b2af794bc4a3869ace23cdd100649e3d6c50dbef1e2fd526c2f284c4c8f7
02_Software/Final_Repository_Snapshot/custom_9dtact/shape_reconstruction/calibration/sensor_1/depth_calibration/ref.png | 1 | 192242 | 7f8deda043f509deeedcda520cdf0e64c0894919c19ae697091882c3c508a877
02_Software/Final_Repository_Snapshot/custom_9dtact/shape_reconstruction/calibration/sensor_1/depth_calibration/sample.png | 1 | 199792 | 23dcba3036a3a9afc968387a4bbba0a9315abea9f88e02b55d639420be70f217
02_Software/Final_Repository_Snapshot/custom_9dtact/shape_reconstruction/calibration/sensor_1/README.md | 1 | 193 | 34d32a3d68a45aa0a5579d9bc38667a5f307740e9f939dc5076cac4818a467fa
02_Software/Final_Repository_Snapshot/custom_9dtact/shape_reconstruction/calibration/sensor_2/camera_calibration/col_index.npy | 2 | 1228928 | f3f22ccf78d15431d178ac6fabb66b44c5a390b3354fb8f485f2533f05737982 | 480x640 | int32 | True
02_Software/Final_Repository_Snapshot/custom_9dtact/shape_reconstruction/calibration/sensor_2/camera_calibration/manual_calibration_report.yaml | 2 | 446 | 58fbceaaa05fd1877fabe2bbf03b4f2e9f8760ccc31c8451297be85b389b2c88
02_Software/Final_Repository_Snapshot/custom_9dtact/shape_reconstruction/calibration/sensor_2/camera_calibration/manual_points.csv | 2 | 1012 | 1504b700f489613fd441e835c611fb9e7dd69a8babe261c724792038716bd945
02_Software/Final_Repository_Snapshot/custom_9dtact/shape_reconstruction/calibration/sensor_2/camera_calibration/manual_points.npy | 2 | 1136 | b03da939f19232dec2ad044eee24705a29c149dcd58692e74af2aa13719dde2e | 63x2 | float64 | True
02_Software/Final_Repository_Snapshot/custom_9dtact/shape_reconstruction/calibration/sensor_2/camera_calibration/position_scale.npy | 2 | 152 | 15c95bf85f6da828832e20ee64da0d195427f11f96918b1795b6a3288326c118 | 3 | float64 | True
02_Software/Final_Repository_Snapshot/custom_9dtact/shape_reconstruction/calibration/sensor_2/camera_calibration/ref.png | 2 | 166152 | 4b3e6788904f57d34f1faf026ea0fda952fea6e216e19c82bae0303d3c30b822
02_Software/Final_Repository_Snapshot/custom_9dtact/shape_reconstruction/calibration/sensor_2/camera_calibration/ref_GRAY.png | 2 | 58345 | 1366ce5ebf094bbbbcb559b56b89d118bd024d4e7c2989dfd5267d2d1e6e976d
02_Software/Final_Repository_Snapshot/custom_9dtact/shape_reconstruction/calibration/sensor_2/camera_calibration/row_index.npy | 2 | 1228928 | f54090298f15e1e706256368d4b3e4308eecae751d241664b082fd61abf8c9aa | 480x640 | int32 | True
02_Software/Final_Repository_Snapshot/custom_9dtact/shape_reconstruction/calibration/sensor_2/camera_calibration/sample.png | 2 | 176775 | d5a3bf01432c261f3a4f190f988f13e572d7877816db9399936c4f903515b141
02_Software/Final_Repository_Snapshot/custom_9dtact/shape_reconstruction/calibration/sensor_2/camera_calibration/sample_drawing.png | 2 | 195341 | 778ac2daf94ffe22be980a05dc92c859265e46699762208a6d8b6c0ad4af1de4
02_Software/Final_Repository_Snapshot/custom_9dtact/shape_reconstruction/calibration/sensor_2/camera_calibration/sample_drawing_manual.png | 2 | 195341 | 778ac2daf94ffe22be980a05dc92c859265e46699762208a6d8b6c0ad4af1de4
02_Software/Final_Repository_Snapshot/custom_9dtact/shape_reconstruction/calibration/sensor_2/camera_calibration/sample_drawing_new.png | 2 | 142814 | 4154cbb71f503a5d181e6ae3d11556aae6276f5793cd0cc18a6765325816e864
02_Software/Final_Repository_Snapshot/custom_9dtact/shape_reconstruction/calibration/sensor_2/camera_calibration/sample_drawing_new_crop.png | 2 | 103068 | 5868aa24f303bc0a7c126bf13ba1629c3a9651890cd2dace788013533fe57982
02_Software/Final_Repository_Snapshot/custom_9dtact/shape_reconstruction/calibration/sensor_2/camera_calibration/sample_drawing_new_crop_manual.png | 2 | 103068 | 5868aa24f303bc0a7c126bf13ba1629c3a9651890cd2dace788013533fe57982
02_Software/Final_Repository_Snapshot/custom_9dtact/shape_reconstruction/calibration/sensor_2/camera_calibration/sample_GRAY.png | 2 | 62552 | 04aeb49f23b82302d1d8cc372eb60d5cfe350c5361939079dd2703b542cfa85f
02_Software/Final_Repository_Snapshot/custom_9dtact/shape_reconstruction/calibration/sensor_2/camera_calibration/sample_new.png | 2 | 125813 | 8a1c053b8d698aa1209cd179633a2af2d8ebf3ba36b9e83c1fb8e740fa4ce31c
02_Software/Final_Repository_Snapshot/custom_9dtact/shape_reconstruction/calibration/sensor_2/camera_calibration/sample_new_crop.png | 2 | 87178 | 5fda8990fd22a298790cb0cc6bbe0e37512234386096614a1a986261d87701a2
02_Software/Final_Repository_Snapshot/custom_9dtact/shape_reconstruction/calibration/sensor_2/depth_calibration/DEPTH_CALIBRATION_SOURCE.md | 2 | 1539 | 5408cc186ba4805130e6a17f6e922f29c865791f3761f8a194e0ad997cceb691
02_Software/Final_Repository_Snapshot/custom_9dtact/shape_reconstruction/calibration/sensor_2/depth_calibration/Pixel_to_Depth.npy | 2 | 616 | 19c9f3514dce402d8e710079757394b5445b74e7afbdd2459de43798676cb4ff | 61 | float64 | True
02_Software/Final_Repository_Snapshot/custom_9dtact/shape_reconstruction/calibration/sensor_2/depth_calibration/rectify_crop_ref.png | 2 | 79538 | e9a4694c1b911850fc034ec6762fce11e88dffee1c9797e4205c58d735ba2fa6
02_Software/Final_Repository_Snapshot/custom_9dtact/shape_reconstruction/calibration/sensor_2/depth_calibration/rectify_crop_sample.png | 2 | 82432 | 3dd6dc1b6ea5d816b9355780df05e70c30f98d7349a0337eaff17eee9331309b
02_Software/Final_Repository_Snapshot/custom_9dtact/shape_reconstruction/calibration/sensor_2/depth_calibration/ref.png | 2 | 251148 | 3fe1f3a307ce45b08fd5fd9c033aa9a47c6e8eecb39a7ca1817e2a3aef6d86a0
02_Software/Final_Repository_Snapshot/custom_9dtact/shape_reconstruction/calibration/sensor_2/depth_calibration/sample.png | 2 | 253993 | da8d6cec8374a6943e000a693a005579bd08b1f8ccb744d4340f6b0605297fd6
02_Software/Final_Repository_Snapshot/custom_9dtact/shape_reconstruction/calibration/sensor_2/README.md | 2 | 193 | dc1b4f5ce21c21343970b2dcecd53847d5dce2f9226edffe1f96e9a785f4cb78

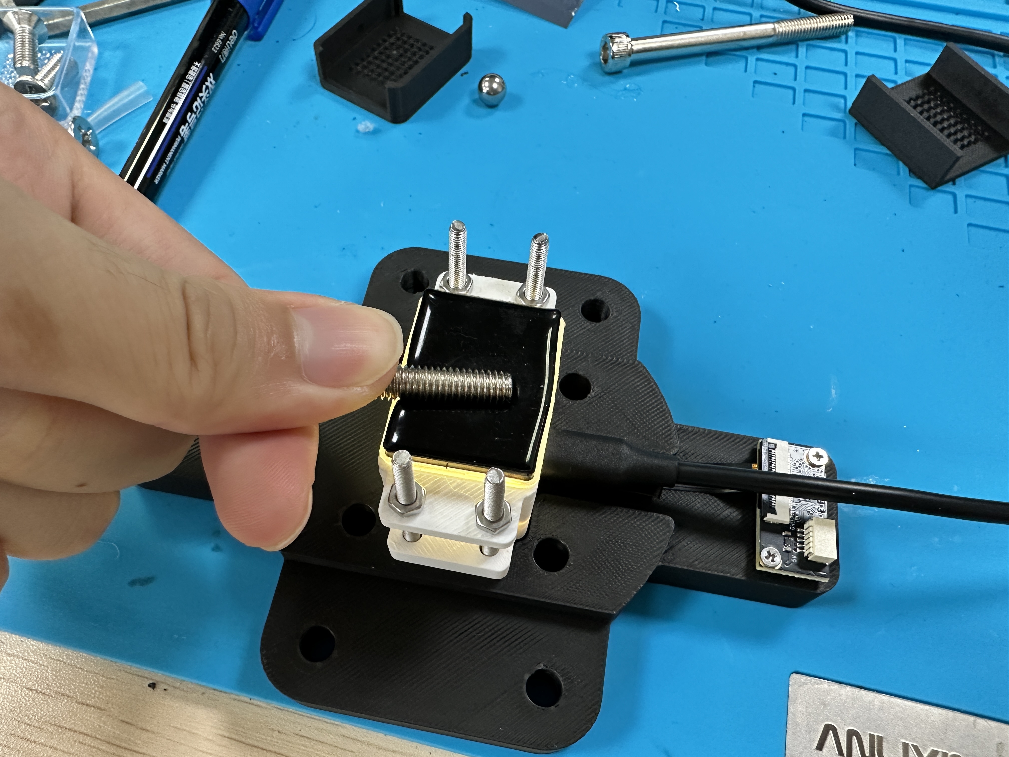
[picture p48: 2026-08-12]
03_Hardware/08_Renders_and_Photos/Test_Setups/screw_loading_sensor_test.jpg

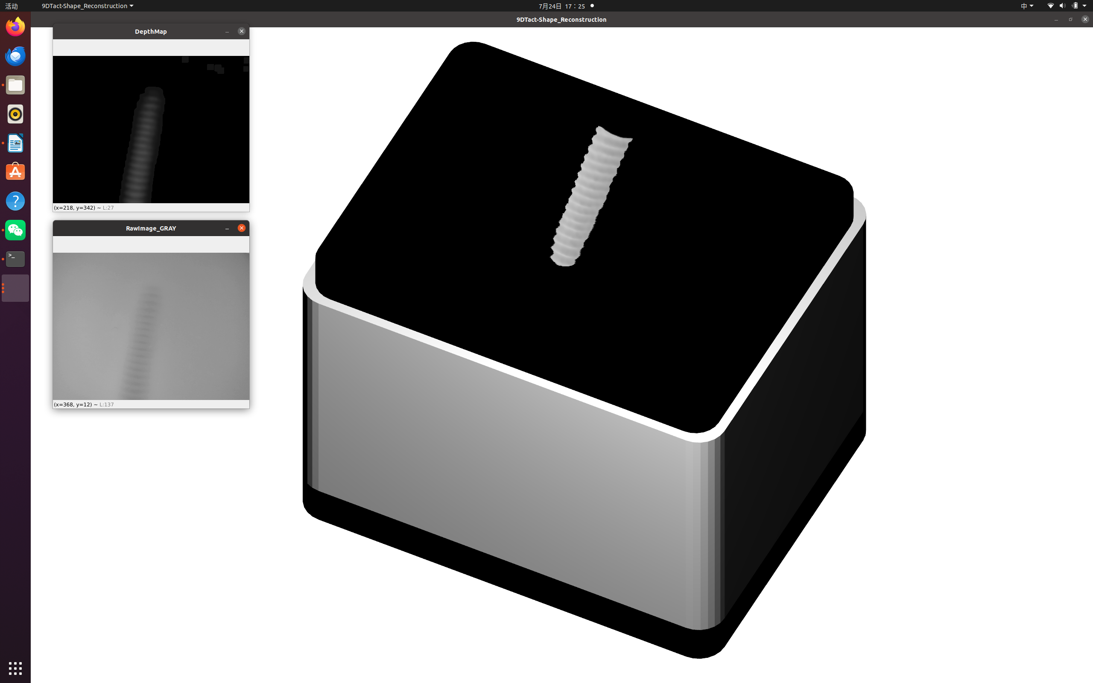
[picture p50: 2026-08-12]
04_Data_and_Models/03_Processed_Data/Shape_Reconstruction_Results/shape_reconstruction_result.png

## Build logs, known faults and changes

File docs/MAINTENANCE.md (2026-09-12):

# 作品集维护记录

## 2026-09-12 英文工程展示与项目命名

- 按用户明确要求，将现有仓库更名为 `compact-vision-tactile-sensor`；项目展示标题为 **Compact Vision-Based Tactile Sensor for Robotic End Effectors**。
- 默认首页改为英文，README_EN 保留兼容入口，README_ZH 提供中文展示；介绍突出结构、光学与布线集成、分层硅胶、两套实物、FT300 平台和夹爪 CAD 方案。
- 首页聚焦工程成果；详细实验条件、文件来源与验证记录继续通过原技术文档查看。既有验证结论和冻结软件未改。
- 更新 About、视频链接、版本身份、维护约束及外层清单；旧仓库名称仅保留在历史记录中。

## 2026-09-12 公开访问验证

- 仓库已作为公开工程作品集发布，固定入口为 `https://github.com/Liiiin-hku/Liuzhaolin_Project`，默认分支为 `main`。
- 不带 Cookie 或 Authorization 的 21 项请求均返回 HTTP 200，覆盖首页、公开仓库信息、中英文说明、硬件/软件/演示导航、6 张展示图和3个短片；16 个原始文件响应与本地文件 SHA-256 相符。
- 访问验证不增加算法、硬件或精度验证结论；原验证状态及软件冻结来源保持不变。

## 2026-09-12 招聘阅读入口优化

- 中英文首页增加 22 秒样机视频、FT300 平台和结构资料的直接入口。
- 增加面向机械设计与硬件集成岗位的阅读顺序；按实际保留文件说明两套样机、原生 CAD、STL 与模具 DXF 的交付范围。
- 不把文件数量解释为完整装配工程，不改变原有个人贡献、软件来源或验证边界。
- 软件、CAD、PCB、标定数组、原始照片和录像保持不变；本次文档调整未重新运行硬件测试。
- 补充检查阶段报告内的第三方媒体：两轮早期调研的 PDF/PPTX 改留技术摘要与来源；两份后续报告仅省略第三方引用图片，分别为 PDF 第 8 页和第 13 页，其余页面渲染一致。
- 保留上游原理图及现有许可，区分早期方案、个人实物工作和上游性能；更新阶段导航与展示修改映射。
- 外层展示历史已按授权定向整理，保留各次提交的演变与技术文件；历史提交 SHA 随之改变。冻结软件来源 commit 和文件字节不变。
- 在 GitHub 页面核对首页展示及三个短片入口；Edge 文件页提供下载而非内嵌播放，已逐一触发下载，并补充直接下载链接与操作说明。这次登录状态下的界面检查不等同于匿名访问验证。

## 2026-09-11 外层作品集整理

- 中英文首页以实物、个人贡献、结构与制造证据为主线；保留五大资料区。
- 新增硬件、视频、项目概览、验证状态和权属导航；原技术交接摘录位于 `docs/archive/HANDOVER.md`。
- 6 张压缩展示图、3 个静音 H.264 连续视频节选均有原件和处理映射；原 CAD、PCB、照片、视频与实验数组保持原路径。
- 论文展示 PDF 去除学号；移出原可编辑论文与内部评审表；参考文献改为两份明确 CC BY 全文加完整书目及官方链接。
- 区分上游 PCB 复用、个人安装与照明集成，取消未核实的 30% 体积缩减和型号归属主张。
- 依据当前数组、配置和代码更新标定及六维力状态；保存原评审中的技术限制。
- 冻结软件 297 个文件不变；来源比较纠正原交接“远端逐字节一致”的说明，换行差异及内部清单差异均已有于原包。
- Windows / Python 3.12 的 30 项离线测试及静态提交验证通过；硬件、Ubuntu/ROS 实机及 SolidWorks 重建未执行。

当前技术状态以 [VALIDATION_STATUS](VALIDATION_STATUS.md) 为准；外层内容以 [根文件清单](../SUBMISSION_MANIFEST.csv) 核对。普通展示维护不自动授权重写 Git 历史或改变访问权限；这些操作须另行通过完整公开检查。

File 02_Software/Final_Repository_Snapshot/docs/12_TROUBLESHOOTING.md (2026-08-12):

# 12 - Troubleshooting

[Previous: ROS workflow](11_ROS_WORKFLOW.md) | [Home](../README.md) | [Next: Project tree](13_PROJECT_TREE.md)

## Start with evidence

Record the exact command, working directory, sensor ID, active configuration, complete
error text, and recent changes. Run the smallest applicable check before repeating a
hardware operation.

## Python or dependency errors

### Wrong Python version

```bash
python --version
```

Use Python 3.8 on Ubuntu 20.04. Recreate the environment rather than modifying a copied
or incompatible virtual environment.

### ROS imports are missing inside the virtual environment

Source Noetic and use a virtual environment created with system site packages:

```bash
source /opt/ros/noetic/setup.bash
source <LOCAL_PROJECT_ROOT>/custom_9dtact/.venv/bin/activate
python <LOCAL_PROJECT_ROOT>/scripts/verify_installation.py --profile ros
```

If the environment was created without `--system-site-packages`, remove only that local
environment after confirming its resolved path, then rerun the bootstrap script.

### PyTorch/CUDA mismatch

```bash
python -c "import torch; print(torch.__version__); print(torch.cuda.is_available())"
nvidia-smi
```

Install a wheel appropriate for the target driver. A CPU wheel is valid for functional
testing but will not provide CUDA acceleration.

## Camera errors

### Camera does not open

```bash
v4l2-ctl --list-devices
ls -l /dev/video*
fuser /dev/video2
```

Correct the selected persistent shape template and reactivate. The archived channel 2
value may differ on the current host.

### No GUI window

Check that the session has a graphical display, OpenCV GUI support, and a valid
`DISPLAY` environment. Remote/headless sessions need an appropriate ROS or file-output
workflow rather than an interactive OpenCV/Open3D program.

### Manual calibration point is wrong

Use right-click or `U` to undo. Press `A` to toggle snapping. After 63 row-major points,
press Enter to preview and `B` to return for corrections. Lowercase `s` is the explicit
save action. `--resume` reloads an incomplete checkpoint; `--no-snap` starts without
local snapping.

### Rectified grid crosses or crop is incomplete

Do not save the preview. Recheck row-major order, border points, orientation, and the
`280 x 380` crop. Restore all three camera arrays from one matching backup if a saved
mapping is worse.

## Depth and shape errors

### Hybrid verifier fails after sensor calibration

`_2_Sensor_Calibration.py` replaces the active LUT, so failure is expected when the
sensor intentionally leaves the official hybrid state. Preserve and label the new LUT.
If restoring the official hybrid experiment, restore both official active LUT copies
without changing camera arrays, then rerun the verifier.

### No-contact surface is noisy or curved

Check reference capture, lighting, focus, mounting, camera mapping, and LUT selection.
Compare backed-up configurations under controlled conditions. Structural array checks
do not diagnose physical depth error.

### Press location or sign is wrong

For location errors, inspect camera row/column mapping and crop. For height sign or
scale errors, inspect the active LUT and sensor response. Do not swap arrays between
sensors as a diagnostic shortcut.

## FT300 and acquisition errors

### Topic has the wrong type or is absent

The external driver must publish `geometry_msgs/WrenchStamped`:

```bash
rostopic type /robotiq_ft_wrench
rostopic echo -n 1 /robotiq_ft_wrench
```

Correct the configured topic or external driver. The repository does not start the
hardware driver.

### Topic checker reports stale or zero timestamps

Correct the publisher's header timestamps and ROS clock configuration. Increasing the
allowed age can hide a synchronization defect and should not be the first response.

### Empty or changing frame ID

Publish a stable physical frame and configure the expected frame. Document the
transform into the tactile frame.

### Zeroing fails or force signs look wrong

Remove contact, allow the system to settle, inspect standard deviation, and review
axis signs, rotation, and translation in `ft300.yaml`. Software zeroing removes offset;
it does not correct scale or geometry.

### Image/wrench pairs are missing

Check image and wrench topic rates, timestamps, `sync_slop`, freshness limits, and
collector logs. Preserve incomplete data until the cause is recorded, then process a
backup copy using the dry-run workflow.

## Dataset and training errors

### Integrity checker reports incomplete triplets

One or more matching image, mixed-image, or raw-wrench files are absent. Return to the
session log and backup. Run normalization dry-run before any destructive apply step.

### Object leakage is detected

Regenerate indices with `split_train_test_by_object.py`. The default force templates
use `test_object: true`; all frames belonging to one object must remain on one side of
the train/test boundary.

### Model cannot find weights

Confirm the selected sensor's `model_choice`, run suffix, epoch, and exact
`saved_models_sensor_X/.../epoch_N.pt` path. Reactivate after editing the persistent
template.

### Model image-size error

Confirm both selected configuration values are `[280, 380]` in height-width order and
that dataset images have the same dimensions.

## ROS errors

### Package is not found

```bash
source /opt/ros/noetic/setup.bash
cd <LOCAL_PROJECT_ROOT>/custom_9dtact/ros_ws
catkin_make
source devel/setup.bash
rospack find nine_dtact_ft300_ros
```

The source folder is named `9dtact_ft300_ros`, but the declared ROS package is
`nine_dtact_ft300_ros`.

### Repository runner cannot locate custom_9dtact

Keep the catkin workspace inside this repository layout or set:

```bash
export NINE_DTACT_PROJECT_ROOT=<LOCAL_PROJECT_ROOT>/custom_9dtact
```

### Node starts but publishes nothing

Check `rosnode info`, `rostopic info`, publisher/subscriber topic names, the camera,
configuration path, and upstream node logs. Verify one stage at a time rather than
starting the combined launch first.

## Escalation record

If a problem remains, preserve:

- exact command and full terminal output;
- `git rev-parse HEAD`;
- sensor ID and configuration copies;
- dependency versions;
- topic names, types, frames, rates, and one sanitized sample;
- calibration and checkpoint hashes;
- a minimal reproduction that does not overwrite data.

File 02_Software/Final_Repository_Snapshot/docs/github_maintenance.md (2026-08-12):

# Repository Maintenance Compatibility Note

This former page is retained only so older links remain valid.

- Repository structure and generated-artifact policy:
  [13_PROJECT_TREE.md](13_PROJECT_TREE.md)
- Offline submission checks: [VERSION_INFO.md](../VERSION_INFO.md)
- Protected hybrid experiment record:
  [ORIGINAL_DEPTH_LUT_EXPERIMENT_2026-07-25.md](ORIGINAL_DEPTH_LUT_EXPERIMENT_2026-07-25.md)

Treat `Original/` as read-only, keep datasets and trained weights outside Git, and run
`python scripts/verify_submission.py` before packaging.

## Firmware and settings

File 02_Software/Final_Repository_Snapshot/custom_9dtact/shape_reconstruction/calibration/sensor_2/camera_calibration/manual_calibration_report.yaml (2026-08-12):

method: manual_7x9_rbf_v2
sensor_id: 2
camera_channel: 2
image_width: 640
image_height: 480
grid_rows: 7
grid_cols: 9
grid_distance_mm: 2.5
center_row: 237.0
center_col: 319.0
mm_per_pixel: 0.05949821080323876
invalid_map_ratio: 0.32837890625
statistics:
  horizontal_median_px: 49.10189677704217
  vertical_median_px: 47.069090651311384
  horizontal_cv: 0.09715092652323523
  vertical_cv: 0.09037299511597818
  center_x: 319.0
  center_y: 237.0

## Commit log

2026-08-12 Initial complete project handover snapshot
    [1_Perception_Module.SLDASM, 2_Diffusion_Module.SLDASM, 3_Contact_Module.SLDASM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]
2026-09-11 docs: present mechanical and hardware portfolio with evidence boundaries
    [HARDWARE_PROVENANCE.csv, LITERATURE_INDEX.csv, REFERENCE_DOWNLOAD_MANIFEST.csv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]
2026-09-12 docs: add direct hardware evidence links for recruiting review
    [SUBMISSION_MANIFEST.csv]
2026-09-12 docs: replace third-party survey media with traceable source summaries
    [REPORT_DISPLAY_EDITS.csv, SUBMISSION_MANIFEST.csv]
2026-09-12 docs: record curated history and preserve software provenance
    [SUBMISSION_MANIFEST.csv]
2026-09-12 docs: document verified GitHub video download workflow
    [SUBMISSION_MANIFEST.csv]
2026-09-12 docs: record public portfolio access verification
    [SUBMISSION_MANIFEST.csv]
2026-09-12 docs: present compact tactile sensor engineering portfolio in English
    [SUBMISSION_MANIFEST.csv]
